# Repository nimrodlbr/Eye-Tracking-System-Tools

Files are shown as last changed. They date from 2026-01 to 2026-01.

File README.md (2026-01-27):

# Eye-Tracking System Tools

Tools for eye-tracking data synchronization, annotation, and analysis.

## Overview

This repository provides tools for synchronizing eye-tracking videos with arena videos and electrophysiology recordings, preprocessing eye-tracking data, and reproducing figures from published research. The synchronization pipeline is designed to work with various recording formats, with Open Ephys provided as a reference implementation.

## Setup

### Prerequisites

- Python 3.10 or higher
- Conda (recommended) or pip

### Installation Options
You have three options for setting up the environment:

#### Option 1: Using Conda Environment (recommanded)

```bash
# Create environment from environment.yml
conda env create -f environment.yml
conda activate eye_repo

# Install package in development mode
pip install -e .
```

#### Option 2: Using pyproject.toml

```bash
pip install -e .
```

This will install the package and all dependencies in development mode.

#### Option 3: Using requirements.txt

```bash
pip install -r requirements.txt
pip install -e .
```

### Verification

Run the smoke test to verify imports:

```bash
python examples/smoke_preprocessing_imports.py
```

## Project Structure

```
src/eye_tracking_system_tools/
├── preprocessing/     # Data synchronization and preprocessing
├── figures/          # Figure reproduction scripts
├── raspberry_pi/      # Raspberry Pi video capture utilities
└── utils/            # General utilities
    ├── 3D_printing_files/  # 3D printing files and virtual fitting guide
    └── meshroom_pipeline_template.mg
```

## Usage

### Figure Reproduction

The figure reproduction scripts are straightforward to use. Each script in `src/eye_tracking_system_tools/figures/reproduction/main_figures/` can be run directly to reproduce the corresponding paper figure.

**Example:**
```bash
cd src/eye_tracking_system_tools/figures/reproduction/main_figures/Fig_1_e
python figure_1e.py
```

**Note:** Supplementary figures reproduction is still a work-in-progress.

### Data Preprocessing and Synchronization

The preprocessing module requires data organized in a specific folder structure that matches the `BlockSync` class expectations.

#### Required Data Structure

The `BlockSync` class expects the following folder structure:

```
path_to_animal_folder/
└── animal_call/
    └── experiment_date/  (format: yyyy_mm_dd, or None for no date paradigm)
        └── block_xxx/
            ├── arena_videos/          # External arena video outputs
            ├── eye_videos/
            │   ├── LE/                 # Left eye videos
            │   │   └── video_folder/
            │   │       ├── video.h264  # Video file
            │   │       ├── video.mp4   # Video file (optional)
            │   │       ├── DLC_analysis_file.csv  # DeepLabCut pupil annotations
            │   │       └── timestamps.csv         # Video timestamps
            │   └── RE/                 # Right eye videos
            │       └── video_folder/
            │           ├── video.h264
            │           ├── video.mp4
            │           ├── DLC_analysis_file.csv
            │           └── timestamps.csv
            ├── oe_files/               # Open Ephys recordings (or custom format)
            │   └── experiment_datetime/
            │       ├── events.csv      # Event data (for Open Ephys)
            │       └── settings.xml    # Recording settings
            └── analysis/               # Output directory (initially empty)
```

#### Pupil Annotations

**Important:** This repository does not provide the pupil annotation model. Users must provide their own pupil annotations that adhere to the DeepLabCut `.csv` export format, with one annotation file per eye video.

If you use a different pupil annotation method, you can work around this requirement by converting your annotations to match the DeepLabCut format, or by modifying the preprocessing code to accept your format.

#### Synchronization Pipeline

**Basic Usage:**

```python
from eye_tracking_system_tools.preprocessing import BlockSync

# Initialize block synchronization
block = BlockSync(
    animal_call="animal_name",
    experiment_date="yyyy_mm_dd",  # or None for no date paradigm
    block_num="001",
    path_to_animal_folder="/path/to/data",
    channeldict=None  # Optional: custom channel mapping
)

# Parse synchronization events
block.parse_open_ephys_events()

# Run synchronization
block.synchronize_block()
```

**Custom Synchronization Paradigms:**

The synchronization pipeline is not limited to Open Ephys recording formats. While Open Ephys is provided as a reference implementation, users can parse their own synchronization paradigm by creating a `parsed_events.csv` file that matches the expected format.

The `parsed_events.csv` file should be a pandas DataFrame (saved as CSV) with the following structure:

- **Timestamp columns:** One column per synchronization channel containing timestamps (e.g., `Arena_TTL`, `L_eye_TTL`, `R_eye_TTL`)
- **Frame columns:** Corresponding frame number columns with `_frame` suffix (e.g., `Arena_TTL_frame`, `L_eye_TTL_frame`, `R_eye_TTL_frame`)

To use a custom synchronization paradigm:

1. Create your `parsed_events.csv` file in the `oe_files/experiment_datetime/` directory
2. Ensure it follows the format described above
3. The `BlockSync` class will automatically detect and use this file if it exists

For detailed examples and advanced usage, see `src/eye_tracking_system_tools/preprocessing/block_synchronization.ipynb`.

## Development

The synchronization module has been migrated to Python 3.10 and tested. Additional modules (annotation/curation, analysis/figure generation) are available and continue to be refined.

## License

See LICENSE file for details.

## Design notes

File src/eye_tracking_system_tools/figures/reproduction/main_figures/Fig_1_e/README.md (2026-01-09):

# Figure 1e: Camera Jitter Quantification

## Description
Histogram of camera movements, quantified as percentage of overall frames in each bin, indicating low camera jitter.

## Data File
- `distances.pkl`: NumPy array containing displacement distances in micrometers (454,300 measurements)

## Reproduction
Run the reproduction script:
```bash
python src/eye_tracking_system_tools/figures/reproduction/main_figures/figure_1e.py
```

This will generate `figure_1e.pdf` in this directory.

## Figure Specifications
- **Type**: Histogram
- **Bins**: 15 bins from 0 to 500 μm
- **Y-axis**: Percentage of frames (%)
- **X-axis**: Displacement (μm)
- **Figure size**: 2 × 1.6 inches
- **DPI**: 150

## Original Pipeline
Created using `deprecated_pipelines_for_reference/figures_creation_jitter_quantification.ipynb`

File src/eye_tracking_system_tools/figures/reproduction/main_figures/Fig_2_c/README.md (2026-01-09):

# Figure 2c: Mean saccade angular speed profiles

## Data File Required

Place the `pos_vel_by_amp_bins_bundle.pkl` file in this directory. This file should be exported from the `main_sequence_analysis.ipynb` notebook.

## Expected Bundle Structure

The pickle file should contain a dictionary with:
- `params`: Dictionary with plotting parameters (fig_size, dpi, lw, etc.)
- `animals`: Dictionary keyed by animal ID, each containing:
  - `series`: List of dictionaries, each containing:
    - `label`: String label for the amplitude bin
    - `color_rgba`: Tuple of (r, g, b, a) color values
    - `vel_center`: Array of velocity values (mean)
    - `vel_lo`: Array of velocity values (lower bound, optional)
    - `vel_hi`: Array of velocity values (upper bound, optional)
    - `time_axis` or `mov_axis`: Array of time values (may need to be reconstructed)

## Usage

```bash
python figure_2c.py
```

The script will generate `figure_2c.pdf` in this directory.

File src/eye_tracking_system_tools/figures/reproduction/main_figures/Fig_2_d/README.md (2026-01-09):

# Figure 2d: Mean angular-displacement traces

## Data File Required

Place the `pos_vel_by_amp_bins_bundle.pkl` file in this directory. This file should be exported from the `main_sequence_analysis.ipynb` notebook.

## Expected Bundle Structure

Same as Figure 2c, but using position data instead of velocity:
- `animals`: Dictionary keyed by animal ID, each containing:
  - `series`: List of dictionaries, each containing:
    - `pos_center`: Array of position values (mean)
    - `pos_lo`: Array of position values (lower bound, optional)
    - `pos_hi`: Array of position values (upper bound, optional)

## Usage

```bash
python figure_2d.py
```

The script will generate `figure_2d.pdf` in this directory.

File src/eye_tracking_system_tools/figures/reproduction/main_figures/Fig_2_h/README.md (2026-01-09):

# Figure 2h: Heatmaps of eye-endpoint densities

## Description

Heatmaps of eye-endpoint densities for concurrent and monocular saccades (single animal) relative to saccade start location. The figure compares synced (concurrent) vs non-synced (monocular) saccade trajectories.

## Data File Required

Place the `figure_2h.pickle` file in this directory. This file should be exported using the `export_figure_2h_data` function from `export_figures_2f_2h_2i_helper.py` in the `multiple_figures_pipeline_migration.ipynb` notebook.

## Expected Data Structure

The pickle file should contain a dictionary with the following keys:

- `figure_name`: String identifier ("figure_2h")
- `synced`: Dictionary with synced (concurrent) saccade trajectories:
  - `R`: Dictionary with right eye data:
    - `x`: np.ndarray of x-coordinates (angular displacement), float32
    - `y`: np.ndarray of y-coordinates (angular displacement), float32
  - `L`: Dictionary with left eye data:
    - `x`: np.ndarray of x-coordinates (angular displacement), float32
    - `y`: np.ndarray of y-coordinates (angular displacement), float32
- `non_synced`: Dictionary with non-synced (monocular) saccade trajectories:
  - `R`: Dictionary with right eye data:
    - `x`: np.ndarray of x-coordinates (angular displacement), float32
    - `y`: np.ndarray of y-coordinates (angular displacement), float32
  - `L`: Dictionary with left eye data:
    - `x`: np.ndarray of x-coordinates (angular displacement), float32
    - `y`: np.ndarray of y-coordinates (angular displacement), float32
- `rotation_catalog`: Optional dictionary mapping (animal, eye) tuples to rotation angle in degrees (for alignment)
- `nbins`: Integer number of bins for the heatmap
- `global_min`: Float minimum value for the heatmap extent
- `global_max`: Float maximum value for the heatmap extent

## Usage

```bash
python figure_2h.py
```

The script will generate `figure_2h.pdf` in this directory.

## Notes

- The x and y arrays represent angular displacements (zeroed to saccade start location)
- Trajectories are pooled across saccades to create density heatmaps
- The `rotation_catalog` may be used to align trajectories if needed
- Both synced and non-synced trajectories use the same extent (`global_min`, `global_max`)

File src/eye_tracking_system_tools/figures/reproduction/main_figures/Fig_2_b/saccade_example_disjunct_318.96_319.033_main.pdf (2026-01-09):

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

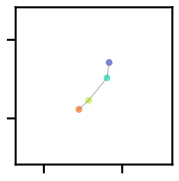
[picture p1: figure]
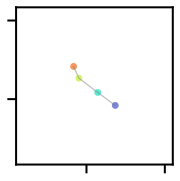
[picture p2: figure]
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

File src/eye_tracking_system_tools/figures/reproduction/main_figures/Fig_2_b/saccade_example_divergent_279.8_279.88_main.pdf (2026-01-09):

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

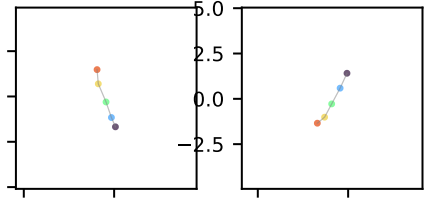
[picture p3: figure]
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

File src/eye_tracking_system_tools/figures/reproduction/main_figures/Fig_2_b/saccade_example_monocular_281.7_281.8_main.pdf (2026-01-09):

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

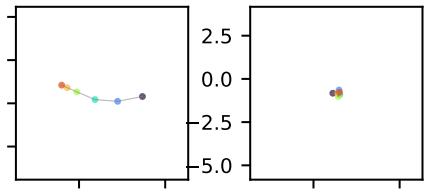
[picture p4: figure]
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

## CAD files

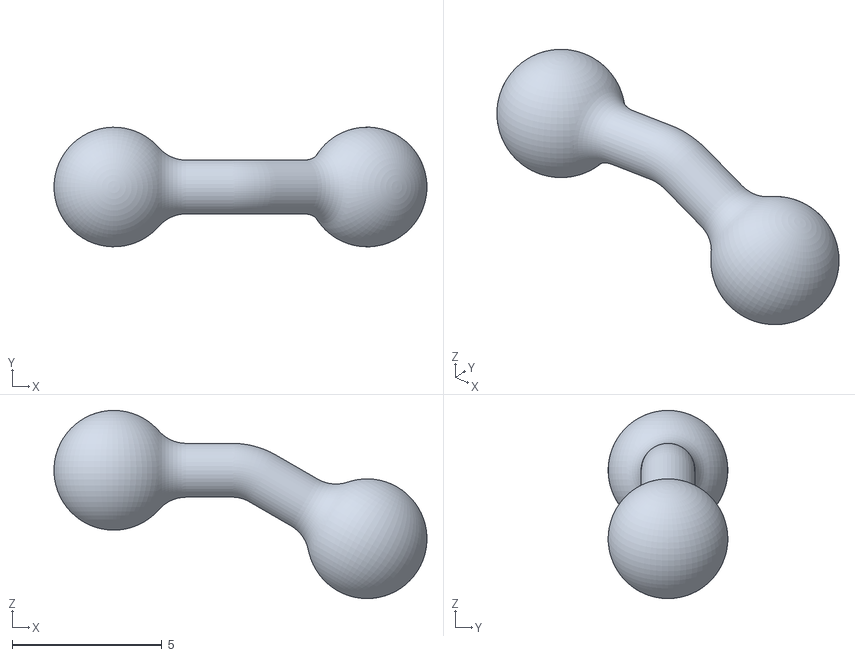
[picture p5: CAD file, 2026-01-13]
src/eye_tracking_system_tools/utils/3D_printing_files/modular/BallPoleKnee_long30.stl
12.5 x 3.99 x 6.29

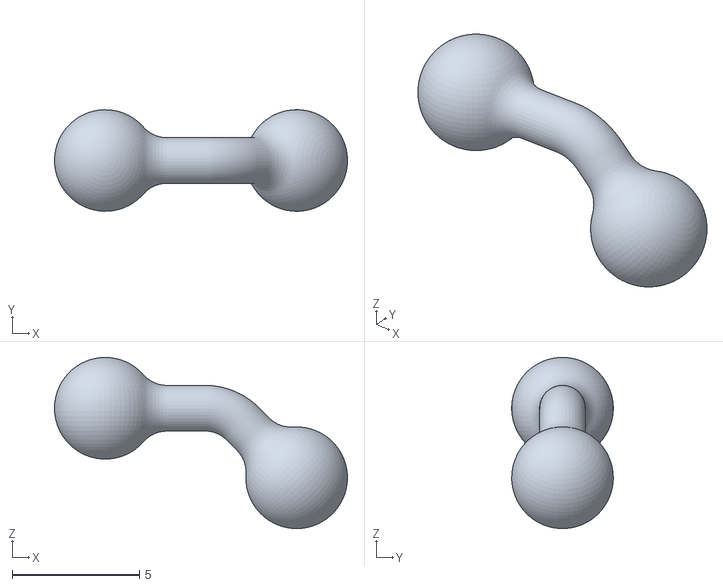
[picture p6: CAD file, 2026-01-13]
src/eye_tracking_system_tools/utils/3D_printing_files/modular/BallPoleKnee_mid45.stl
11.5 x 3.99 x 6.73

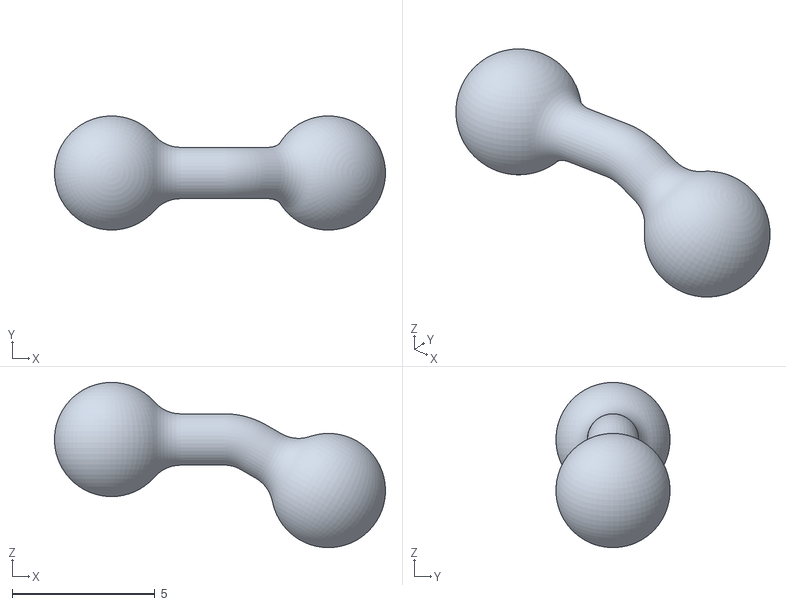
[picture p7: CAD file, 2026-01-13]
src/eye_tracking_system_tools/utils/3D_printing_files/modular/BallPoleKnee_mid30.stl
11.6 x 3.99 x 5.79

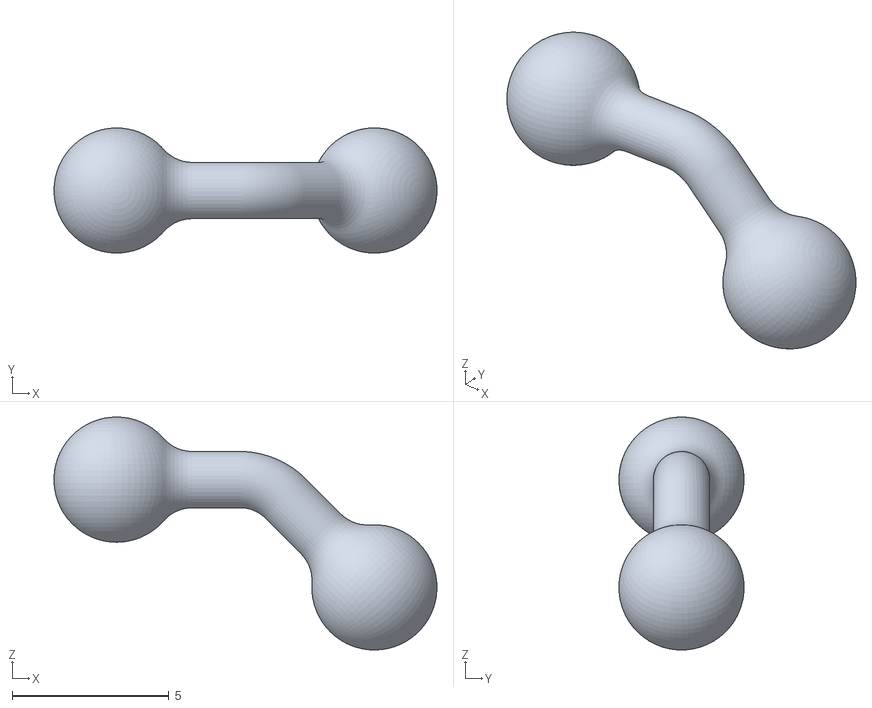
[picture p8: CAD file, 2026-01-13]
src/eye_tracking_system_tools/utils/3D_printing_files/modular/BallPoleKnee_long45.stl
12.2 x 3.99 x 7.44

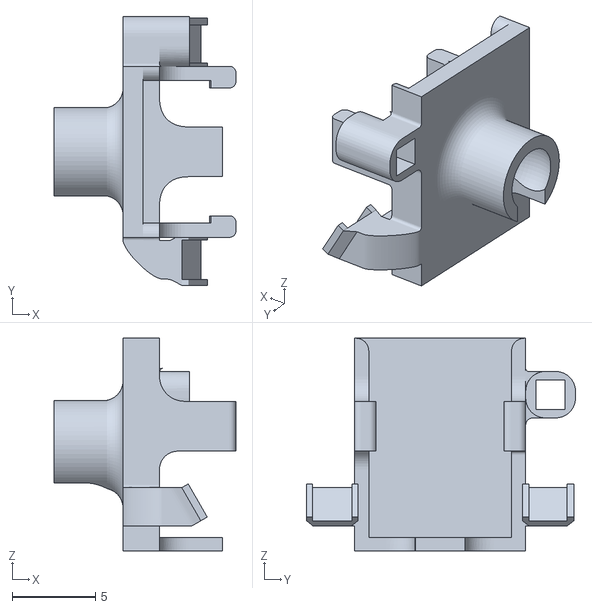
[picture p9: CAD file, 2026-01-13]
src/eye_tracking_system_tools/utils/3D_printing_files/modular/CamHolder_left.stl
11.0 x 16.2 x 12.8

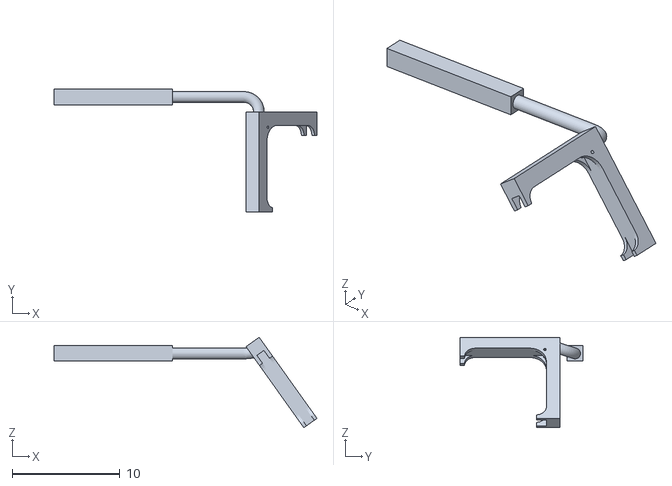
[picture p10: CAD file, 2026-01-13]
src/eye_tracking_system_tools/utils/3D_printing_files/modular/MirrorHolder_left.stl
24.4 x 11.4 x 8.40

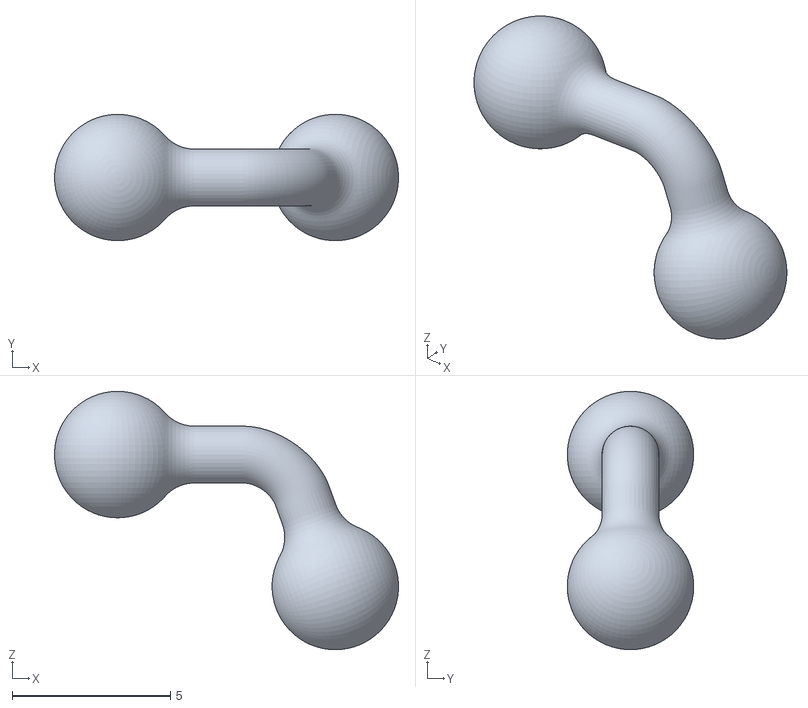
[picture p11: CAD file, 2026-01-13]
src/eye_tracking_system_tools/utils/3D_printing_files/modular/BallPoleKnee_mid70.stl
10.9 x 3.99 x 8.17

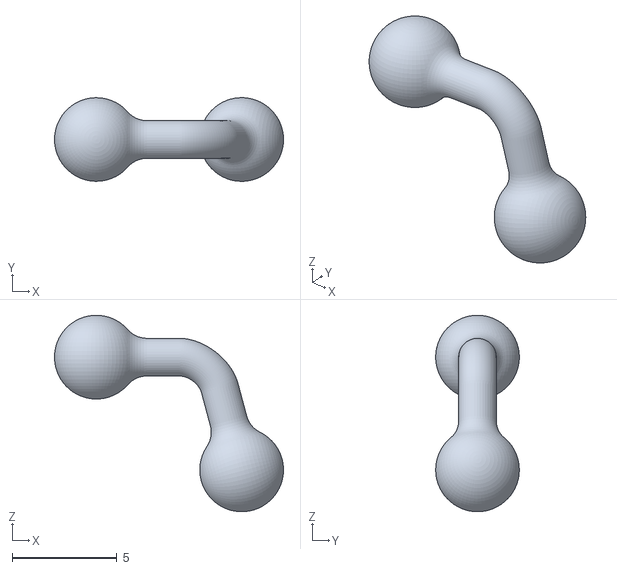
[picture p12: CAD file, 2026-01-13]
src/eye_tracking_system_tools/utils/3D_printing_files/modular/BallPoleKnee_long70.stl
10.9 x 3.99 x 9.38

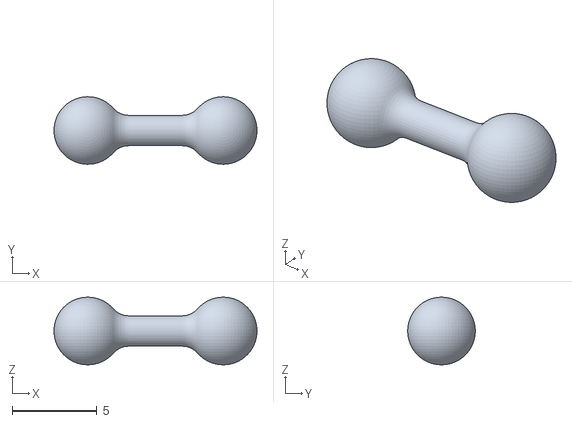
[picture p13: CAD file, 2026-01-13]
src/eye_tracking_system_tools/utils/3D_printing_files/modular/BallPole_10mm.stl
12.0 x 3.99 x 4.00

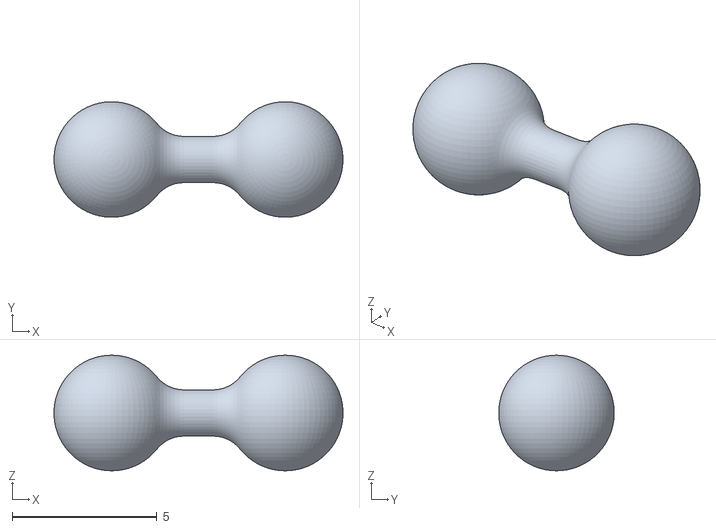
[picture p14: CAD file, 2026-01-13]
src/eye_tracking_system_tools/utils/3D_printing_files/modular/BallPole_10mm_n2.stl
9.99 x 3.99 x 4.00

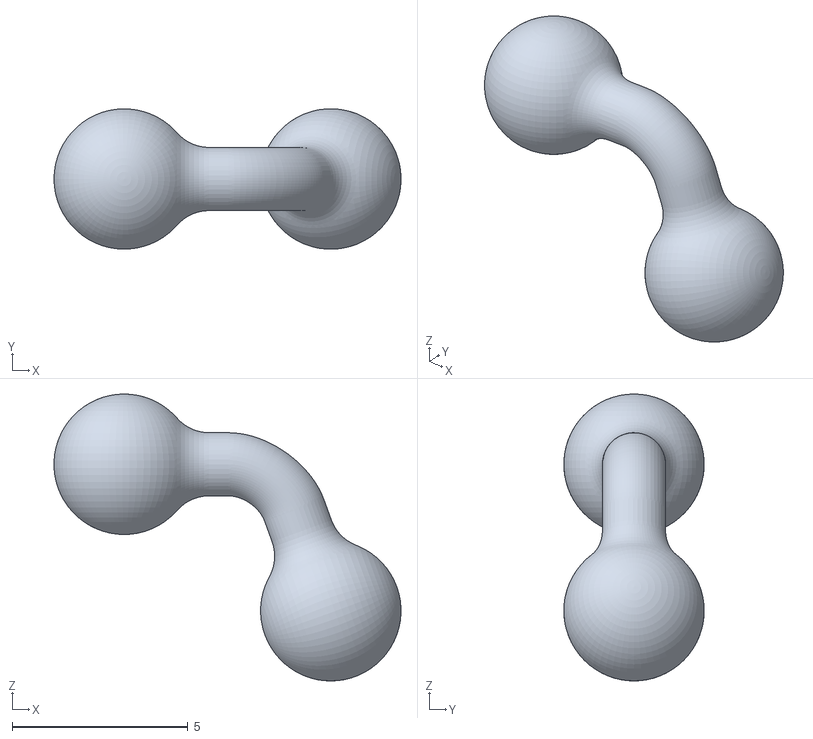
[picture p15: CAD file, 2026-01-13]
src/eye_tracking_system_tools/utils/3D_printing_files/modular/BallPoleKnee_Short70.stl
9.88 x 3.99 x 8.17

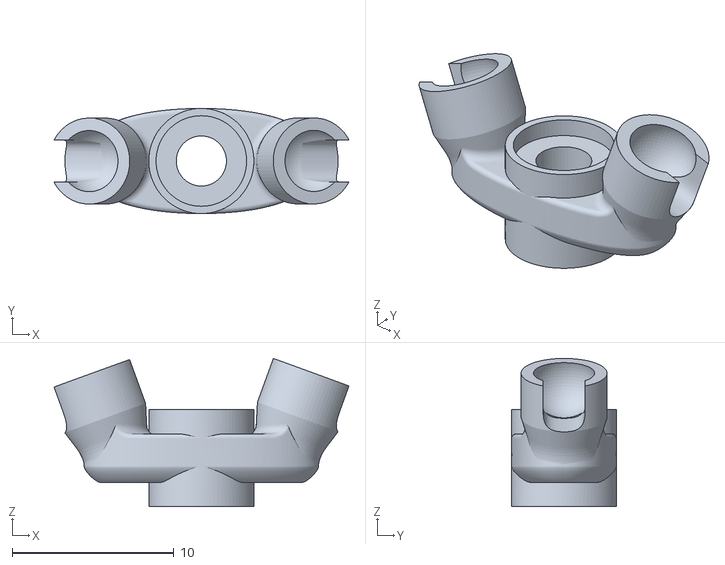
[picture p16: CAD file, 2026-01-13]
src/eye_tracking_system_tools/utils/3D_printing_files/modular/HexBaseWBallSockets.stl
18.2 x 6.50 x 9.16

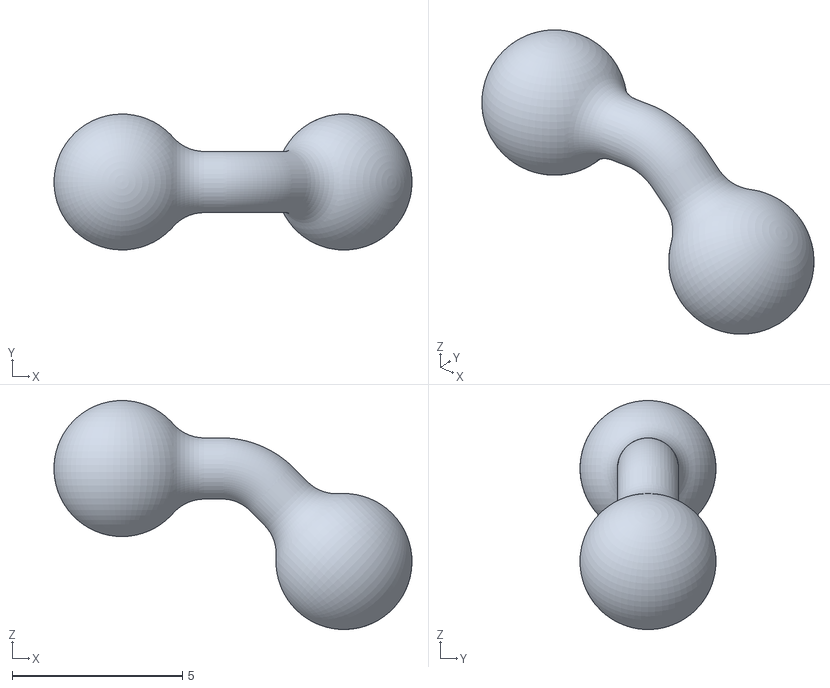
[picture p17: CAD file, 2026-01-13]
src/eye_tracking_system_tools/utils/3D_printing_files/modular/BallPoleKnee_Short45.stl
10.5 x 3.99 x 6.73

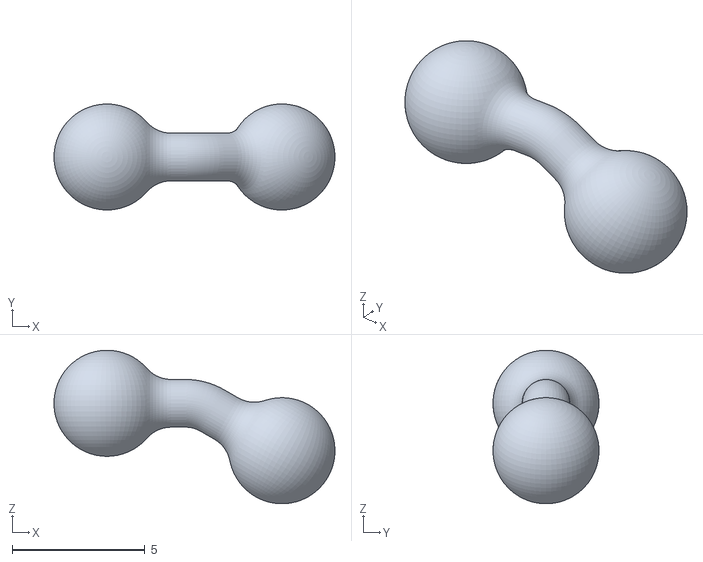
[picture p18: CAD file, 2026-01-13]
src/eye_tracking_system_tools/utils/3D_printing_files/modular/BallPoleKnee_short30.stl
10.6 x 3.99 x 5.79

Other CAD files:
src/eye_tracking_system_tools/utils/3D_printing_files/modular/MirrorHolder_right.stl
src/eye_tracking_system_tools/utils/3D_printing_files/modular/HexBaseWBallSockets_Mice_4point1mm_socket.stl
src/eye_tracking_system_tools/utils/3D_printing_files/modular/BallPole_Shortest.stl
src/eye_tracking_system_tools/utils/3D_printing_files/modular/CamHolder_right.stl

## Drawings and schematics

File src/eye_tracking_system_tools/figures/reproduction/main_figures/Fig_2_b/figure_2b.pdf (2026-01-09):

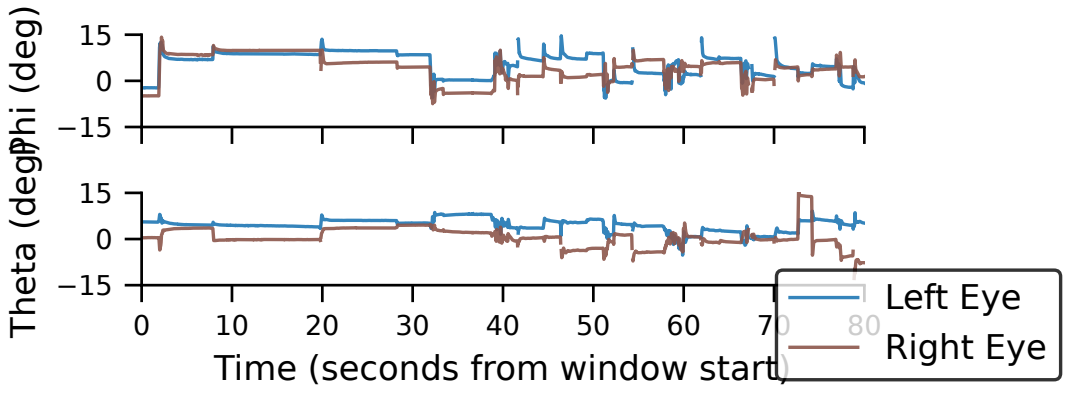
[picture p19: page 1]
Phi (deg); Time (seconds from window start); Theta (deg); Left Eye Right Eye

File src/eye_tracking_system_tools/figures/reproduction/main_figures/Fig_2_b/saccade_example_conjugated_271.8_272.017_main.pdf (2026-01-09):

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

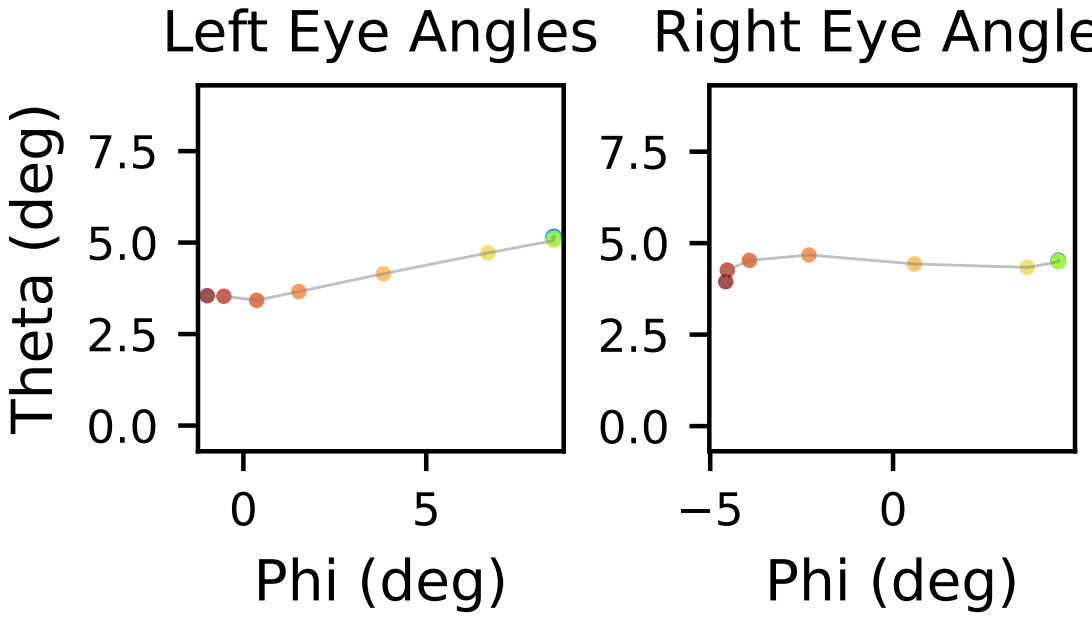
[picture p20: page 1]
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

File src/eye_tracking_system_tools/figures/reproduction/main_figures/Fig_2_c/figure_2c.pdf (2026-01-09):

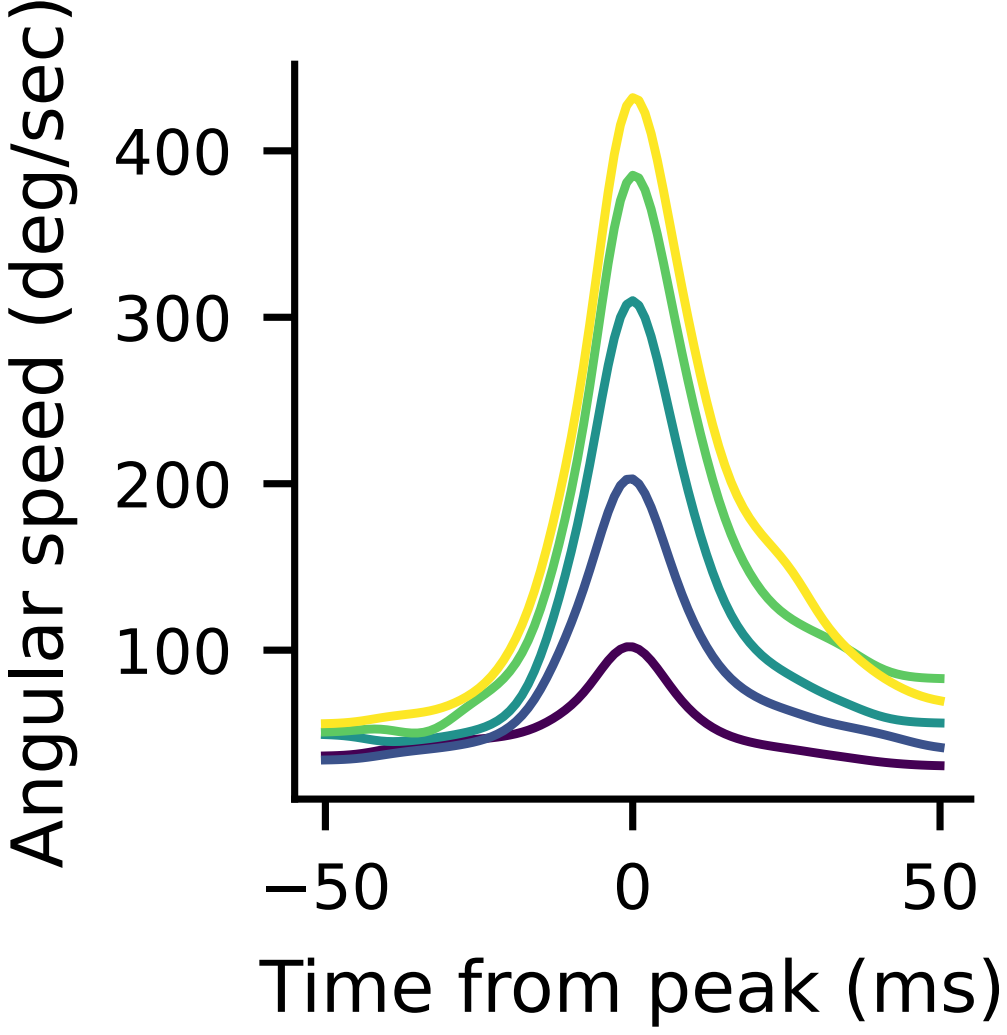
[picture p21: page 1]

Angular speed (deg/sec)

Time from peak (ms)

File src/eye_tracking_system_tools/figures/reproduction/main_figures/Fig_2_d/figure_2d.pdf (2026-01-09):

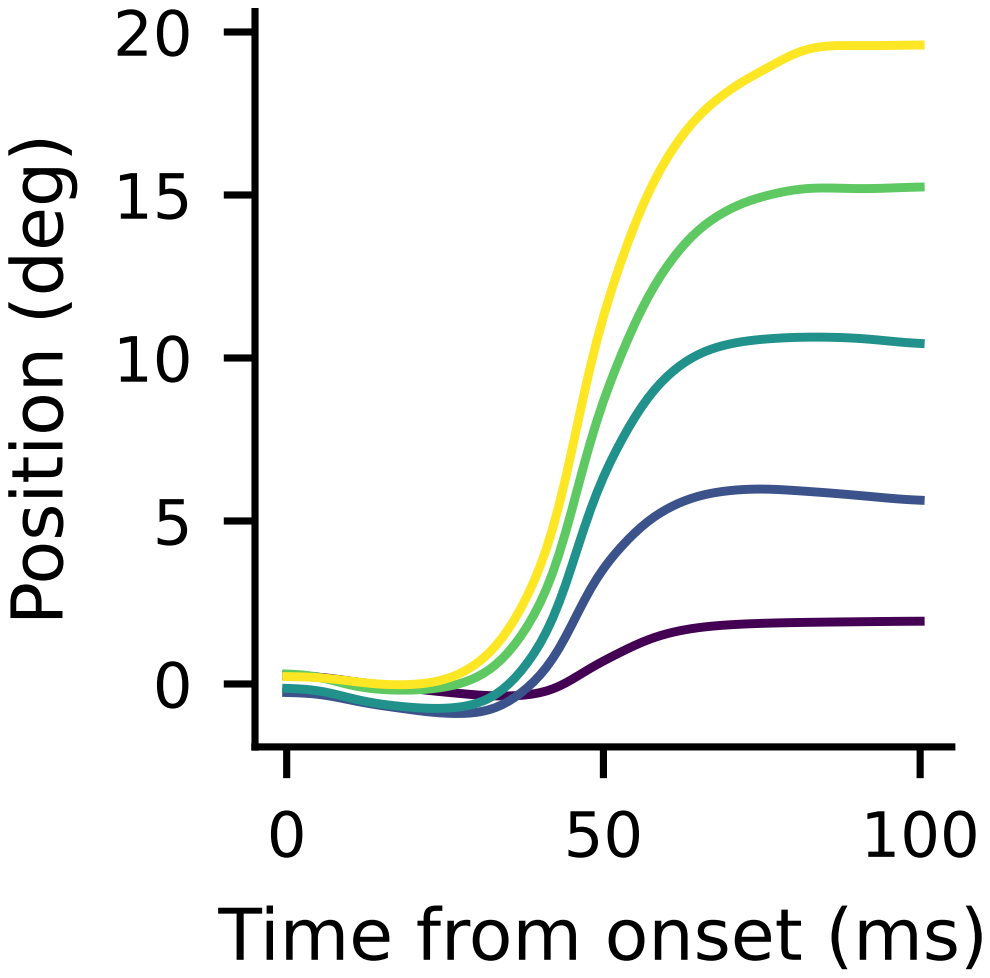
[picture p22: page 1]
Position (deg)

Time from onset (ms)

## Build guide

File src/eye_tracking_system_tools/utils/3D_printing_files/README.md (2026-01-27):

# Virtual Fitting Guide

**Applies to:** `Virtual_Fitting_Main.f3d` in this repository

## Goal of the Workflow

You will:
- **(A)** Import an animal head mesh (reference only)
- **(B)** Position the left and right camera rigs so each points at its eye
- **(C)** Create TWO lofts connecting the fixed hex base to the left/right loft plates
- **(D)** Export ONE combined "single-print headstage" body as an STL

### What You Should NOT Do

- Remodel the camera rigs, unless you use a different camera
- Edit or rebuild the hex base, unless you have a different anchor interface (the existing hex base component is for a standard 3M hexagonal spacer, but can be remodeled to fit any anchor; this and camera holder remodeling requires some know-how and will not be covered here)
- Move individual camera/mirror bodies directly (move the aim components instead)

## Component Map (What Moves vs What Stays Fixed)

### Fixed / Should Stay Put

- **hex_base:1** - The anchor base; treat as the world reference

### Movable "Rig Handles" (These are the ONLY things you should move)

- **left_aim:1** - Moves camera/mirror/axes for the LEFT eye together
- **right_aim:1** - Moves camera/mirror/axes for the RIGHT eye together

### Helpful Reference Items

- **EyeBall1, EyeBall2** - Visual guides; optional for comfortable alignment

### Typical Contents (Do Not Edit Unless You Know Why)

**left_aim:1** contains bodies like:
- camera_holder
- loft_interface_plate_l
- mirror / mirror holder parts
- construction axes: cam_axis, cam_axis_reflection

**right_aim:1** contains bodies like:
- camera_holder_r
- Loft_interface_plate_r
- construction axes: cam_axis_r, reflection_axis_r

## Step-by-Step Instructions

### 1) Open and Sanity-Check the Design

#### 1.1 Open the Fusion File

- File → Open → select `Virtual_Fitting_Main.f3d`

#### 1.2 In the Browser, Confirm the Following

- You can see: `left_aim:1`, `right_aim:1`, `hex_base:1`
- Only `left_aim:1` and `right_aim:1` should be moved during fitting
- `hex_base:1` should remain fixed in position

#### 1.3 (Optional but Recommended) Create a "Working Copy"

- File → Save As…
- Name it: `Virtual_Fitting_{animalID}_{YYYYMMDD}_fit.f3d`

---

### 2) Import the Animal Mesh (Reference Only)

**Goal:** Bring in your animal model so you can aim the cameras in context.

#### 2.1 Insert the Mesh

- Insert → Insert Mesh
- Choose your mesh file (STL/OBJ)

#### 2.2 Put the Imported Mesh into Its Own Component

- If Fusion creates a MeshBody at the root, right-click it → Create Components from Bodies
- Rename the component to: `animal_mesh_{animalID}`

#### 2.3 Scale the Mesh to Correct Size (Choose ONE Method)

**Method A (Preferred):** Scale using the implanted hex anchor on the animal
- Use the known physical dimension of the hex anchor (across-flats, etc.)
- Measure the same dimension on the mesh (Inspect → Measure)
- Compute scale factor = (real dimension) / (measured mesh dimension)
- Modify → Scale (select the animal mesh component)

**Method B:** Scale using a known anatomical landmark distance
- Example: known distance between two landmarks you can measure on the mesh
- Same workflow: measure → compute scale factor → scale

#### 2.4 (Optional Comfort Step) Place the Reference Eyeballs

Fusion may not carry complex textures well, so use simple geometry as visual guides.
- Position EyeBall1 / EyeBall2 roughly into the eye sockets of the mesh
- This is optional: it is only a visual aid, not required

---

### 3) Aim the Camera Rigs (Move ONLY the Aim Components)

**Goal:** Each camera is oriented toward its respective eye with a sensible inclination angle.

#### 3.1 IMPORTANT RULE

Move only:
- `left_aim:1`
- `right_aim:1`

Do NOT drag individual bodies inside these components.

#### 3.2 Reposition/Rotate Left Camera Rig

- Activate the "Move/Copy" tool (Modify → Move/Copy)
- Selection: choose the COMPONENT `left_aim:1` (not bodies)
- Translate/rotate until the camera's optical path points to the left eye

#### 3.3 Reposition/Rotate Right Camera Rig

- Same process with `right_aim:1`

#### 3.4 Use the Construction Axes as a Precise Aiming Cue

- `left_aim:1` contains "cam_axis" (camera forward axis) and "cam_axis_reflection"
- `right_aim:1` contains "cam_axis_r" and "reflection_axis_r"

#### 3.5 Choose Inclination Angle Carefully

- Avoid extreme angles that will collide with the animal mesh or reduce mirror clearance
- Ensure both rigs have enough physical clearance for printing and mounting
- If needed, hide the animal mesh temporarily to check for rig intersections

---

### 4) Create the Two Lofts (hex_base → Loft Interface Plates)

**Goal:** Create a single printable headstage by joining geometry.

You will do TWO loft operations:
- **Loft #1:** hex_base circular cutoff → left loft interface plate
- **Loft #2:** hex_base circular cutoff → right loft interface plate

#### 4.1 Loft to LEFT Interface Plate

- Create → Loft
- Profiles: select
  - (a) the circular connection cutoff face/edge on `hex_base:1` (left side)
  - (b) the matching profile on `loft_interface_plate_l` (inside `left_aim:1`)
- Operation: set to "Join"
- Confirm: OK

#### 4.2 Loft to RIGHT Interface Plate

- Create → Loft
- Profiles: select
  - (a) the circular connection cutoff face/edge on `hex_base:1` (right side)
  - (b) the matching profile on `Loft_interface_plate_r` (inside `right_aim:1`)
- Operation: set to "Join"
- Confirm: OK

#### 4.3 Verify You Now Have a Single Printable Body

- In the Browser, check Bodies: you should see one combined body (or one per join if not yet merged)
- If you see multiple separate bodies:
  - You likely used "New Body" instead of "Join"
  - Undo and redo the loft(s) with Operation = Join

---

### 5) Export STL for Printing

#### 5.1 Hide Everything That Should NOT Be Printed

Turn off visibility for:
- `animal_mesh_{animalID}`
- EyeBall1 / EyeBall2
- Any non-print helper geometry

#### 5.2 Select Only the Final Printable Body

- Right-click the combined headstage body → Save as Mesh (or 3D Print)

#### 5.3 Export Settings (Typical)

- Format: STL (Binary)
- Refinement: High (or Custom if you need smaller file size)
- Units: confirm match your printer workflow (mm is typical)

#### 5.4 Name the STL Using the Scheme

```
headstage_singlepiece_{animalID}_{YYYYMMDD}.stl
```

---

## Troubleshooting

### A) "When I Move One Camera, Other Stuff Moves Too"

- Make sure you are moving the COMPONENT `left_aim:1` or `right_aim:1` (not a body)
- Quick test: expand `left_aim:1` and `right_aim:1` then select the top component name and move it

### B) "Loft Fails or Produces Twisted Geometry"

- Check you selected the correct matching profiles (left cutoff ↔ left plate; right cutoff ↔ right plate)
- Confirm the profiles are planar and not self-intersecting
- Try selecting edges (profile loops) instead of faces if face selection is ambiguous

### C) "Loft Created a New Body Instead of Joining"

- In Loft dialog: Operation must be "Join"
- If Join is unavailable, you may be lofting to a body that Fusion does not consider intersecting: try extending loft, check profile orientation, or confirm both targets are solid bodies

### D) "My Mesh is Huge/Tiny"

- Your scale factor is likely wrong or units are mismatched
- Re-check the real-world dimension you used (mm vs cm)
- Use Inspect → Measure on the mesh after scaling to confirm

### E) "Exported STL Includes Extra Objects"

- Make sure you selected ONLY the final headstage body when exporting
- Hide everything else before export as a safety measure

---

## Best-Practice Tips for a Robust Workflow

- Keep the animal mesh as reference-only. Do not convert it to BRep unless you must
- Rename your working copy file per animal/date so you can reproduce a fit
- Move ONLY `left_aim:1` and `right_aim:1`. This preserves the internal rig relationships
- After you position rigs, consider creating a Named View ("Left fit", "Right fit") for reproducibility
- If you change anything structural, bump the PATCH version and update this guide alongside the .f3d

---

## Checklist (Quick Validation Before Export)

- [ ] `hex_base:1` has not moved
- [ ] `left_aim:1` points at the left eye; `right_aim:1` points at the right eye
- [ ] Two lofts exist and BOTH are Operation = Join
- [ ] Final result is one printable combined body
- [ ] Animal mesh and helper components are hidden
- [ ] STL exported with correct units and filename

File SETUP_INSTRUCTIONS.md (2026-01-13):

# Setup Instructions for eye_repo Environment

## Quick Setup

1. **Activate your existing conda environment:**
   ```bash
   conda activate eye_repo
   ```

2. **Verify Python version:**
   ```bash
   python --version
   # Should show: Python 3.10.19
   ```

3. **Install/update dependencies:**
   ```bash
   pip install -r requirements.txt
   pip install -e .
   ```

4. **Verify pathlib is available:**
   ```bash
   python -c "import pathlib; print('OK')"
   ```

## Jupyter Notebook Setup

**Important**: Make sure your Jupyter notebook is using the `eye_repo` kernel:

1. **Install ipykernel in the eye_repo environment:**
   ```bash
   conda activate eye_repo
   pip install ipykernel
   ```

2. **Register the environment as a Jupyter kernel:**
   ```bash
   python -m ipykernel install --user --name eye_repo --display-name "Python (eye_repo)"
   ```

3. **In Jupyter/VS Code:**
   - Select the kernel: "Python (eye_repo)" or "eye_repo"
   - In VS Code: Press `Ctrl+Shift+P` → "Python: Select Interpreter" → Choose the `eye_repo` environment

## Troubleshooting

### If pathlib import fails:
- Make sure you're using Python 3.4+ (pathlib is standard library)
- Check that you're in the correct conda environment: `conda activate eye_repo`
- Verify the interpreter: `which python` (Linux/Mac) or `where python` (Windows)

### If imports fail:
- Reinstall the package: `pip install -e .`
- Check Python path: `python -c "import sys; print(sys.path)"`
- Verify the package is installed: `pip list | grep eye-tracking`

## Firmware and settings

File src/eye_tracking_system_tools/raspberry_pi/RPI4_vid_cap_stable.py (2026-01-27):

#!/usr/bin/env python3
# -*- coding: utf-8 -*-
"""
RPi Camera Recorder with per-frame TTL strobe, live status, optional fixed exposure/ISO,
and HDMI preview window.

Usage:
  python3 capture_with_prev.py \
      --framerate 30.0 --name session_name --quality 23 -t 10 --preview \
      [--auto-exposure|-ae] [--exposure-time|-et 10000] [--iso 200]
"""
import argparse
import signal
import time
import json
import csv
import os
import threading
from pathlib import Path

from picamera2 import Picamera2, Preview
from picamera2.encoders import H264Encoder
import RPi.GPIO as GPIO

# GPIO / TTL Setup
TTL_PIN = 11  # BOARD numbering
GPIO.setwarnings(False)
GPIO.setmode(GPIO.BOARD)
GPIO.setup(TTL_PIN, GPIO.OUT, initial=GPIO.LOW)

# Globals
frame_counter = 0
timestamps = []
stop_event = threading.Event()

# Signal Handler
def signal_handler(sig, frame):
    print("\nReceived Ctrl+C -> stopping...")
    stop_event.set()
signal.signal(signal.SIGINT, signal_handler)

# Preview Mode Helper
def determine_preview_mode(preview_requested: bool):
    """
    If preview_requested, configure an HDMI QtGL preview window,
    maximizing to full screen via wmctrl hack.
    """
    if not preview_requested:
        return None
    print("Enabling fullscreen HDMI preview window")
    os.environ["DISPLAY"] = ":0"
    os.environ["QT_QPA_PLATFORM"] = "xcb"
    # QtGL preview ignores QT_FULLSCREEN, we'll maximize via wmctrl
    return Preview.QTGL

# Status Reporter Thread
def status_reporter(start_time: float):
    while not stop_event.wait(5.0):
        elapsed = time.monotonic() - start_time
        fps = frame_counter / elapsed if elapsed > 0 else 0.0
        print(f"[STATUS] Elapsed: {elapsed:.1f}s | Frames: {frame_counter} | FPS: {fps:.2f}")

# Main Recording Routine
def run_recording(
    framerate: float,
    name: str,
    quality: int,
    duration: float,
    preview_requested: bool,
    auto_exposure: bool,
    exposure_time: int | None,
    iso: int | None,
):
    print(f"run_recording: fps={framerate}, name={name}, quality={quality}, duration={duration}, preview={preview_requested}")
    # Prepare output dirs
    session_dir = Path("./RPiCameraVideos") / name
    session_dir.mkdir(parents=True, exist_ok=True)
    h264_path = str(session_dir / f"{name}.h264")
    info_path = str(session_dir / f"{name}_info.json")
    timestamps_path = str(session_dir / f"{name}_timestamps.csv")

    # Fixed frame duration
    frame_dur_us = int(1_000_000 / framerate)
    controls = {"FrameDurationLimits": (frame_dur_us, frame_dur_us)}
    if not auto_exposure:
        if exposure_time is not None:
            controls["ExposureTime"] = exposure_time
        if iso is not None:
            controls["AnalogueGain"] = iso / 100.0
    print(f"Controls: {controls}")

    # Initialize camera
    picam2 = Picamera2()
    # Configure recording + display main stream
    config = picam2.create_video_configuration(
        main={ 'size': (640, 480), 'format': 'YUV420' },
        display='main',
        controls=controls
    )
    print(f"Configuring camera: {config}")
    picam2.configure(config)
    print("Camera configured")

    # TTL callback per frame
    def ttl_strobe(request):
        global frame_counter, timestamps
        frame_counter += 1
        meta = request.get_metadata()
        ts = meta.get("SensorTimestamp", int(time.time() * 1e9)) / 1e9
        timestamps.append(ts)
        GPIO.output(TTL_PIN, GPIO.HIGH)
        time.sleep(0.0003)
        GPIO.output(TTL_PIN, GPIO.LOW)
    picam2.post_callback = ttl_strobe

    # Start preview
    preview_mode = determine_preview_mode(preview_requested)
    if preview_mode:
        print(f"Starting preview ({preview_mode})")
        picam2.start_preview(preview_mode)
        # Helper: maximize the preview window via wmctrl
        def maximize_preview():
            time.sleep(1.0)  # wait for window to appear
            os.system(
                'wmctrl -r "Picamera2 Preview" '
                '-b add,maximized_vert,maximized_horz'
            )
        threading.Thread(target=maximize_preview, daemon=True).start()

    # Launch status thread
    print(f"Recording to {h264_path} @ {framerate} fps")
    start_time = time.monotonic()
    threading.Thread(target=status_reporter, args=(start_time,), daemon=True).start()

    # Encoder
    try:
        encoder = H264Encoder(quality=quality)
    except TypeError:
        encoder = H264Encoder()
    print(f"Encoder: {encoder}")

    # Start recording
    picam2.start_recording(encoder, h264_path)
    print("Recording started")

    # Run until done or interrupted
    try:
        if duration > 0:
            stop_event.wait(duration)
        else:
            stop_event.wait()
    finally:
        stop_event.set()
        print("Stopping recording...")
        picam2.stop_recording()
        if preview_mode:
            picam2.stop_preview()
        GPIO.cleanup()

        # Save timestamps
        with open(timestamps_path, 'w', newline='') as f:
            writer = csv.writer(f)
            writer.writerow(["time_sec"] )
            for t in timestamps:
                writer.writerow([t])
        # Save metadata
        info = {
            "name": name,
            "framerate": framerate,
            "quality": quality,
            "duration": duration,
            "frame_duration_us": frame_dur_us,
            "start_time": start_time,
            "preview": preview_requested,
            "auto_exposure": auto_exposure,
            "frames_recorded": frame_counter
        }
        with open(info_path, 'w') as f:
            json.dump(info, f, indent=2)
        print(f"Saved video: {h264_path}")
        print(f"Saved timestamps: {timestamps_path}")
        print(f"Saved metadata: {info_path}")

# CLI Entrypoint
if __name__ == "__main__":
    parser = argparse.ArgumentParser(
        description="RPi Camera Recorder w/ TTL strobe + live status + optional exposure/ISO",
        formatter_class=argparse.ArgumentDefaultsHelpFormatter
    )
    parser.add_argument("--framerate", type=float, default=30.0,
                        help="Target recording frame rate (fps)")
    parser.add_argument("--name", type=str, default="video",
                        help="Session name (folder & file prefix)")
    parser.add_argument("--quality", type=int, default=23,
                        help="Encoder quality parameter, if supported")
    parser.add_argument("-t", "--time", type=float, default=10.0,
                        help="Duration (s); -1 for infinite")
    parser.add_argument("--preview", action="store_true",
                        help="Enable HDMI fullscreen preview")
    parser.add_argument("-ae", "--auto-exposure", action="store_true",
                        help="Use automatic exposure/gain")
    parser.add_argument("-et", "--exposure-time", type=int, default=None,
                        help="Manual exposure time (us)")
    parser.add_argument("--iso", type=int, default=None,
                        help="Manual ISO (100->1x gain)")
    args = parser.parse_args()
    run_recording(
        framerate         = args.framerate,
        name              = args.name,
        quality           = args.quality,
        duration          = args.time,
        preview_requested = args.preview,
        auto_exposure     = args.auto_exposure,
        exposure_time     = args.exposure_time,
        iso               = args.iso,
    )

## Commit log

2026-01-13 clean up preprocessing folder for public release- Consolidated StrEnum compatibility into _enum_compat.py - Consolidated bokeh_plotter into utility_functions.py - Removed duplicate code and unused im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
2026-01-13 populated utils folder with 3d assets and meshroom pipeline
    [g__CorrectSocketDepth_Camholder v44_CamHolder_Left.stl, g__CorrectSocketDepth_Camholder v44_CamHolder_Right.stl, g__CorrectSocketDepth_Camholder v44_MirrorHold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]
2026-01-15 corrected modules in .yml and .toml, added raspberry pi 4 video capture code
    [RPI4_vid_cap_stable.py]
2026-01-27 3D models for modular solution, Virtual fitting environment and guide added
    [BallPoleKnee_Short45.stl, BallPoleKnee_Short70.stl, BallPoleKnee_long30.stl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]
